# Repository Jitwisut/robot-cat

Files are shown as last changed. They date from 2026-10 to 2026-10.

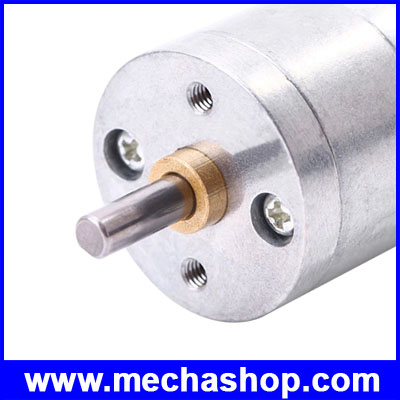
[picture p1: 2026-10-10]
robot_v4/print_revision/catalog/evidence/FromFactory_DCM068_listing_photo_2.jpg

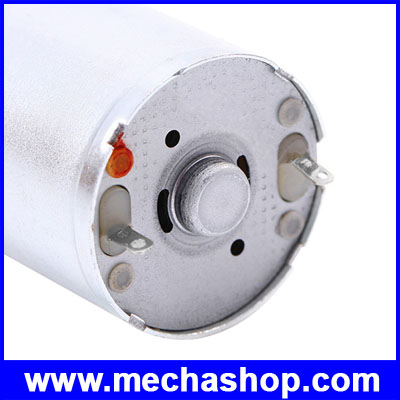
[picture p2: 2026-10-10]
robot_v4/print_revision/catalog/evidence/FromFactory_DCM068_listing_photo_1.jpg

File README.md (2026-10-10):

**Robot V4 R3 (10 ต.ค.2026):** [ชุด CAD/ทดลอง/ขอราคาและงานที่ยังต้องปิด](robot_v4/print_revision/r3/README.md) — DRAFT, ยังไม่พร้อมส่งพิมพ์ชุดเต็ม

# robot-cat — ESP32 Mini BattleBot (V2 robot2 / V3 R3)

CAD, Fusion 360 scripts and reduced-order simulations for a mini battlebot. Current direction is V4 (≤2 kg, ≤6,000 THB per the competition rules; older V2/V3 studies assumed ~1.5 kg).
Project status (Thai): [`STATUS.md`](STATUS.md).
**ทดสอบฟิสิกส์ V4 บน PC (MuJoCo + Fusion Simulation):** [`SIM_ON_PC.md`](SIM_ON_PC.md). Nothing here is cleared for manufacture yet; no 3D FEA has been solved.

| Folder | Contents |
|---|---|
| `exports/` | V2 (`robot2`) CAD exports, reports, impact screening, lifter linkage analysis (`v2_linkage_2026-09-30/`) |
| `robot_v3/` | V3 study: R1–R3 CAD (F3D/STEP), build scripts, reports, robot2 vs R3 duel model (`duel_sim/`) |
| `robot_v4/` | V4 vertical beater: CAD, sizing (`design_v4.py`), matchup screen, ESP32 firmware, status (`robot_v4/STATUS.md`), reduced-order three-way sim (`three_way_sim/`), MuJoCo 3D duel sim (`mujoco_sim/`, needs `python3 -m venv .venv && .venv/bin/pip install mujoco numpy "imageio[ffmpeg]"`) |
| `fusion_scripts/` | Fusion 360 Python scripts that built/edited `robot2`; `V2_Lifter_Stops/` adds the lifter hard stops |

## Latest CAD

**แนว Robot v4 ที่ล็อกตามคำสั่งผู้ใช้ (10 ต.ค. 2026):** Z ขึ้น, พื้น XY ที่ Z=0 ใต้ล้อ, ด้านหน้า +Y ห้ามหมุนโมเดลหรือสลับแกนเพื่อให้เข้ากับค่าเริ่มต้นของโปรแกรม เปิดไฟล์ Fusion ด้านล่างเพื่อใช้ Top/Home ที่ตรวจแล้ว ข้อกำหนดถาวรอยู่ใน [`AGENTS.md`](AGENTS.md)

| Robot | File |
|---|---|
| V4 Print R3 — approved flat Fusion view (DRAFT) | [`ROBOT_V4_PRINT_R3_FUSION_Z_UP.f3d`](robot_v4/print_revision/r3/output_R3/DRAFT/ROBOT_V4_PRINT_R3_FUSION_Z_UP.f3d) |
| V2 with lifter stops (recommended) | `exports/robot2_lifter_stops_2026-10-01.f3d` / `.step` |
| V2 as of items 1–3 | `exports/robot2_items_1_3_2026-09-24.f3d`, `exports/robot2_items_1_3_active_lifter_2026-10-01.step` |
| V3 R3 lifting wedge | `robot_v3/ROBOT_V3_R3_Lifter.f3d` / `.step` |
| V4 Print R1 (draft; measured parts and shop evidence pending) | `robot_v4/print_revision/output/DRAFT/ROBOT_V4_PRINT_R1.step` — [`print preparation`](robot_v4/print_revision/README.md) |
| V4 vertical beater (current direction) | `robot_v4/ROBOT_V4_Beater.f3d` / `.step` |

Axes differ: **V2 is Z-up, nose +Y**; **V3 files are Y-up, nose −Z**. STEP units are mm.
Other `robot2_*.f3d` files in `exports/` are earlier checkpoints; `exports/STL`, `exports/DXF` and `ESP32_Mini_BattleBot_*.step` predate the lifter.

## Re-run the models

```bash
pip install numpy matplotlib
python3 robot_v3/duel_sim/duel_sim.py
python3 exports/v2_linkage_2026-09-30/v2_linkage.py
```

Fusion scripts run from Utilities → Scripts and Add-Ins. Several older scripts write to absolute macOS paths and check for a document named `robot2`.

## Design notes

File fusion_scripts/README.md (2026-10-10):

# Fusion scripts for `robot2`

## Robot v4 R3 viewer orientation

`OrientV4PrintR3.py` sets the active `ROBOT_V4_PRINT_R3` document's Top to +Z and Home to an oblique view above the XY floor. It does not rotate or translate components and does not change global Fusion preferences. It exports a local F3D without saving to the cloud. Use `robot_v4/print_revision/r3/output_R3/DRAFT/ROBOT_V4_PRINT_R3_FUSION_Z_UP.f3d` to reopen the corrected view; a STEP import may inherit Fusion's Y-up document orientation.

Checked on 2026-10-10: all 70 occurrence transforms and assembly bounds were unchanged. Reimporting the F3D retained camera up `(0,0,1)` and showed the grid beneath the wheels. The images `ROBOT_V4_PRINT_R3_FUSION_Z_UP.png` and `ROBOT_V4_PRINT_R3_FUSION_REOPENED.png` record both checks. This fixes the viewing orientation only; R3 retains its DRAFT manufacturing status.

The current `robot2` document is saved in Fusion with the wedge lifter visible. Its seven root occurrences use identity transforms, and the document's ViewCube Top is +Z. This puts the base on Fusion's XY layout grid and makes the front/top Home view show the robot lying flat. The backup is `../exports/robot2_grid_aligned.f3d`; the checked image is `../exports/views/robot2_flat_preview.png`. The original vertical spinner and optional grabber are available as modular groups; see `../exports/Modular_Weapons_Design_2026-09-24.md`. The beater concept is archived at `../exports/robot2_beater_concept_v1.f3d`.

- RestoreOriginalVerticalSpinner.py — one-time replacement of the beater with the original 6 mm axial bar and rotation envelope.
- AddWedgeLifterOption.py — one-time creation of the 62 mm spatula, 6 mm pivot and actuator envelopes.
- AddGrabberOption.py, CutGrabberPivotBores.py — one-time optional upper jaw and pivot bore creation.
- ShowVerticalSpinnerOption.py, ShowWedgeLifterOption.py, ShowGrabberOption.py — set alternative group visibility; check the ESC holder when switching.
- `OrientRobotFlat.py`, `SaveRobotFlat.py` — one-time correction and save of the current XY-grid pose. Do not rerun them on the saved document.
- `OrientRobotToGrid.py`, `DiagnoseAlignment.py` — historical Y-up/XZ-grid trials. **Do not run on the current document**; they rotate the robot upright in the corrected Z-up view.
- CheckWedgeLifterOption.py, CheckGrabberOption.py — read-only stationary interference checks; envelopes and hidden spinner hardware are excluded as applicable.
- SaveOriginalSpinnerOption.py, SaveWedgeLifterOption.py, SaveGrabberOption.py — save robot2 and export the three F3D alternatives.

- `FingerTechSwitchRevision.py` — one-time replacement of the old switch mock; expects the old `Main_Disconnect` and posts.
- `CompetitionVariant.py` — one-time removal of the `04_Top_Hammer` group.
- `FingerTechAccessRevision.py` — one-time replacement of the 20×16 mm top-cover cutout with a Ø6 mm access hole.
- `AlignCompetitionVariant.py` — historical Y-up/XZ-grid alignment. **Do not run on the current Z-up document**.
- `generate_competition_reports.py` — reads the exported JSON snapshot and regenerates current dimensions and mass reports; it does not modify Fusion.
- `BeaterConceptRevision.py` — one-time 34 mm wide beater concept and 34 mm sweep envelope; replaces the old bar. It is guarded against rerunning.
- `CheckBeaterConcept.py` — read-only bounding boxes, mass and interference check for the beater concept.
- `SaveBeaterConcept.py` — saves `robot2` and exports the F3D archive.
- `HighlightBeaterVisual.py` — gives the beater a red appearance while retaining Aluminum 7075 mass.
- `CleanBeaterView.py`, `RestoreBeaterAlignment.py` — historical beater-view helpers; the alignment helper is for the obsolete Y-up pose.
- `ExportBeaterRotorSTEP.py` — exports only the beater rotor concept as STEP.
- `mcp_local.py`, `export_beater_check.py`, `capture_fusion_view.py` — local helpers for the Fusion MCP server on port 27182.
- `BattleBotFixes.py` — historical script for the old assembly. It refuses to run on the current competition variant.

The geometry creation and migration scripts are one-time operations. Do not rerun them on the current document. Verify geometry, interference, group transforms, visibility and saved state before replacing exports.

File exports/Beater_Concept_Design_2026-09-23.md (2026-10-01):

# Beater bar แนวตั้ง — ต้นแบบใน `robot2`

อัปเดต 2026-09-23. บันทึก `robot2` ใน Fusion แล้ว และส่งออก `robot2_beater_concept_v1.f3d`. แบบนี้เป็น **การศึกษาพื้นที่และมวล CAD** ยังไม่ใช่อาวุธพร้อมผลิตหรือหมุนทดสอบ.

อัปเดตการแสดงผล 2026-09-24: ใส่ appearance สีแดงเฉพาะ beater และซ่อนสเกตช์ที่รบกวนภาพ เพราะชิ้นนี้อยู่ใต้ฝาและระหว่างปีกหน้า จึงมองจากมุมบนได้ยาก. ภาพล่าสุดคือ `views/robot2_beater_clear_final.png`. วัสดุยังเป็น Aluminum 7075 และมวล CAD ไม่เปลี่ยน. ส่งออก F3D ใหม่หลังจัดแนว Assembly ขนานกริดแล้ว.

## สิ่งที่เปลี่ยนใน Fusion

- แทน `Spinner_Bar` เดิม (กว้างตามแกน 6 มม., มวล CAD 21.693 กรัม) ด้วย `Beater_Rotor_Concept` เป็นกรอบ beater สองรางเปิดช่องกลาง กว้างตามแกน **34 มม.** วัสดุใน CAD `Aluminum 7075` และมวล **58.166 กรัม**.
- ขนาดโรเตอร์ในแกนโลก: X = -20…14 มม., Y = 28.5…48.5 มม., Z = -107.5…-42.5 มม. เส้นผ่านศูนย์กลางกวาดตามแนวหน้า/หลังยังเป็น **65 มม.** เท่ารุ่นเดิม.
- ช่องเปิดกลางตัดทะลุโรเตอร์เพื่อให้เหลือแก้มด้านข้าง nominal 4 มม. และรางปะทะที่ปลายสองด้าน nominal 10 มม. รูเพลา Ø4 มม. เป็นเพียงรูเช็กตำแหน่งกับเพลาปัจจุบัน **ยังไม่มีข้อต่อถ่ายทอดแรงบิดที่ยืนยันได้**.
- แทน `Spinner_Sweep_Envelope` ด้วย `Beater_Sweep_Envelope` กว้าง 34 มม. ซ่อนไว้ใน Fusion; เป็น solid วิเคราะห์ **ไม่ใช่ชิ้นงาน และต้องตัดออกจากการรวมมวล**.
- เก็บ `robot2_pre_beater_concept.f3d` ไว้ย้อนกลับก่อนเปลี่ยนใบ.

## ผลตรวจจาก Fusion

| รายการ | ผล |
|---|---:|
| ช่องว่างจากขอบโรเตอร์ซ้ายถึงฐานรองซ้าย | 2.5 มม. |
| ช่องว่างจากขอบโรเตอร์ขวาถึงรอกอาวุธ | 2.0 มม. |
| จุดต่ำสุดของวงกวาดเหนือผิวบนฐาน | 1.0 มม. |
| จุดสูงสุดของวงกวาดใต้ฝาบน | 12.0 มม. |
| มวล CAD ทั้งหุ่น ไม่รวม analysis envelopes | 1,070.643 กรัม |
| เพิ่มมวล CAD จากการเปลี่ยนใบ | 36.473 กรัม |
| จำนวน bodies ที่ตรวจ | 55 |

ผล `analyzeInterference` จาก Fusion พบ 2 คู่ คือ `Beater_Sweep_Envelope` กับโรเตอร์และเพลา ซึ่งคาดหมายจากปริมาตรวิเคราะห์. **ไม่พบการซ้อนทับของชิ้นงานจริงในท่าที่จัดไว้**. ผลดิบอยู่ใน `beater_concept_check.json`.

## ไฟล์

- `robot2_beater_concept_v1.f3d` — Assembly รุ่นแนวคิด; เอกสาร `robot2` ใน Fusion บันทึกแล้ว.
- `Beater_Rotor_Concept.step` — เฉพาะโรเตอร์สำหรับแลกเปลี่ยน CAD; **ไม่ใช่ไฟล์ส่งร้านผลิต**.
- `views/robot_beater_concept_attack_side.png` — ภาพมองจากด้านอาวุธ.
- `beater_concept_check.json` — bounding boxes, มวล CAD และคู่ interference.

ไฟล์ STEP ทั้ง Assembly ของรุ่นนี้ยังไม่มี; การส่งออกทั้งโมเดลในรอบแรกไม่จบภายในเวลาที่ตั้งไว้ แต่ F3D และ STEP เฉพาะโรเตอร์ส่งออกได้.

## งานวิศวกรรมที่ต้องทำก่อนเป็นแบบผลิต

1. ออกแบบ **การยึดโรเตอร์กับเพลา** ที่ถ่ายทอดแรงบิดและรับแรงกระแทกได้; รู Ø4 มม. อย่างเดียวไม่พอ. ประเมินว่าจะคงหรือเพิ่มขนาดเพลา แล้วเลือกตลับลูกปืน/รอก/แท่นรองให้สอดคล้องกัน.
2. ตรวจความแข็งแรงของแก้ม 4 มม. และรางปะทะ 10 มม. พร้อมมุมโค้งในช่องเปิดที่ผลิตได้จริง. ออกแบบการถ่วงสมดุลและตรวจรอยร้าวหลังทดสอบ.
3. ตรวจ clearance ที่แคบ โดยเฉพาะวงกวาดเหนือฐานเพียง 1 มม. ภายใต้การงอของเพลา, ระยะประกอบ และแรงกระแทก. รัศมี 32.5 มม. ใน CAD ยังไม่รวมความคลาดเคลื่อน.
4. ยืนยันมอเตอร์อาวุธ, ESC, อัตราทด/สายพาน, เวลาเร่งและหยุด และผลต่อการบังคับเลี้ยวด้วยของจริง. ยังไม่กำหนดรอบหรือพลังงานเป้าหมายจากมวล CAD นี้.
5. เปลี่ยนชุดขับ TT, ทำ failsafe และตัวล็อกอาวุธ; ชั่งชิ้นส่วนจริงทั้งหมด. มวล CAD ไม่ใช่น้ำหนักลงแข่ง.

แนวทางเลือก beater และข้อแลกเปลี่ยนอยู่ใน `Weapon_Upgrade_Review_2026-09-23.md`. การหมุนอาวุธจริงต้องเกิดในสนามปิดที่ผู้จัดรับรอง.

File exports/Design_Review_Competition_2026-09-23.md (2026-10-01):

# ทบทวนแบบหุ่น BattleBot สำหรับแข่งของคณะ

ค้นข้อมูล 2026-09-23. ผู้ใช้แจ้งว่ายังไม่มีกติกาเป็นลายลักษณ์อักษร และอนุญาตให้เปลี่ยนแบบอาวุธได้. ใช้เป้าหมายเดิม 1.5 กก. เป็น **เป้าหมายออกแบบชั่วคราว** ไม่ใช่การรับรองว่าตรงกติกาคณะ.

## แบบที่เลือกใน CAD ตอนนี้

**ตัวถังทรงลิ่ม + ขับ 2 ล้อ + กรงจักรแนวตั้งด้านหน้าเพียงอาวุธเดียว.** ถอดค้อนบนแบบจำลองออกแล้ว เพราะเพิ่มความสูง 50 มม. เหนือฝาและเพิ่มมวล CAD 86.42 กรัม โดยยังไม่มีการยืนยันว่าระบบ servo/แขนค้อนจะรับแรงกระแทกจริงได้. โมเดลมีอาวุธที่ควบคุมได้หนึ่งชุดตามตัวอย่างกติกา Robot Battle Arena 1.5 กก. ของ MIT Media Lab กรุงเทพฯ ปี 2025 ซึ่งกำหนดอาวุธควบคุมด้วยรีโมทอย่างน้อยหนึ่งชุดและสวิตช์เปิด/ปิดมือ แต่กติกานี้ **ไม่ใช่กติกางานคณะ**. [กติกา MIT Media Lab](https://www.media.mit.edu/events/ai-robotics-competition/)

| ทางเลือก | เหมาะเมื่อ | ผลต่อแบบปัจจุบัน | ข้อสรุป |
|---|---|---|---|
| กรงจักรแนวตั้งหนึ่งชุด + ปีก/แผ่นหน้าถอดเปลี่ยนได้ | ต้องการโจมตีและคุมหน้าหุ่น | ใช้ layout เดิม ต้องเสริมเพลา/ยึดใบมีด/ตัวล็อกและแก้ชุดขับ | **เลือกเป็นรุ่นแข่งหลัก** |
| ลิ่ม + lifter แบบ servo หรือ gearmotor | สนามไม่มีตู้ป้องกันสำหรับอาวุธหมุน หรืออยากเน้นควบคุม | ต้องออกแบบคันยก/จุดหมุนใหม่ แต่ลดความเสี่ยงของอาวุธหมุน | เก็บเป็นทางเลือกสำรอง |
| กรงจักร + ค้อน + อาวุธที่สาม | ต้องการหลายบทบาท | ใช้พื้นที่ น้ำหนัก ช่องสัญญาณ และเวลาซ่อมมากขึ้น | ไม่เพิ่มในรุ่นนี้ |

การไม่เพิ่มอาวุธชิ้นที่สามเป็น **การตัดสินใจด้านแบบ** ไม่ใช่ข้อห้ามจากกติกา. สำหรับหุ่น 1.5 กก. คู่มือ Bristol Bot Builders อธิบายว่า servo เหมาะกับ lifter/grabber ส่วน brushless เหมาะกับ spinner และแนะนำให้ทำระบบขับที่ปลอดภัยก่อนเพิ่มอาวุธ. [คู่มือ BBB](https://bristolbotbuilders.com/guides/)

## จุดที่ควรเปลี่ยนถัดไป เรียงตามผลต่อการแข่ง

1. **เปลี่ยนชุดขับ TT ก่อนเพิ่มพลังอาวุธ.** TT motor ทั่วไปที่แบบใช้อยู่เป็นเกียร์พลาสติก 3–6 V; แบต 3S เต็มประมาณ 12.6 V. การตั้ง PWM ประมาณ 50% ไม่ได้ยืนยันความทนของมอเตอร์หรือเกียร์ในการชน. [สเปก TT จาก Adafruit](https://www.adafruit.com/product/3777) แนะนำมอเตอร์เกียร์โลหะ 12 V ที่ออกแบบสำหรับ beetleweight เช่น BBB Planetary 22 mm 16:1 เป็น **ตัวเลือกให้เทียบ** ไม่ใช่สั่งซื้อทันที: ผู้ผลิตระบุ 63×22×22 มม., 61 กรัม, 750 rpm ที่โหลดพิกัด/12 V และกระแส stall 4.3 A. ต้องตรวจร้านที่หาได้จริง, แรงบิด, เพลา/ล้อ และขนาด CAD ก่อนเปลี่ยนรูฐาน. [BBB 22 mm motor](https://shop.bristolbotbuilders.com/product/22mm/)
2. **จับคู่ไดรเวอร์กับมอเตอร์ใหม่.** DRV8874 carrier ที่เลือกไว้จ่ายต่อเนื่องราว 2.1 A ต่อบอร์ดและมี current regulation. ก่อนล็อก 22 mm motor ต้องทดสอบโหลด/อุณหภูมิและดูว่าการจำกัดกระแสกระทบแรงขับมากเพียงใด; หากไม่พอให้เลือกไดรเวอร์ใหม่แล้วแก้ holder/สายไฟ. [Pololu DRV8874](https://www.pololu.com/product/4035)
3. **ทำกรงจักรให้เป็นชุดผลิตและซ่อมได้.** ปัจจุบันใบมีด 65×20×6 มม., เพลา 4 มม., roll pin Ø2 และสายพาน 1:1 ยังเป็น layout; จุดยึดใบมีด/เพลา ความแข็งแรงของเพลา/ลูกปืน ความตึงสายพาน และสมดุลยังไม่ผ่านการทดสอบ. ไม่เพิ่มอัตราทดหรือมวลใบมีดจนกว่าจะตรวจกับผู้มีประสบการณ์และสนามที่มีตู้ป้องกัน.
4. **เสริมหน้าหุ่นแบบถอดเปลี่ยนได้.** ปีกหน้ากลวง 2.5 มม. ใน CAD ผลิตจาก DXF แผ่นเดียวไม่ได้. ทำแบบวิธีผลิตจริง และทดลองแผ่นหน้า/ปลายลิ่มที่เปลี่ยนง่ายหลังเห็นพื้นสนาม; อย่าใส่ปลายที่เสี่ยงเกี่ยวพื้นก่อนวัด ground clearance. คู่มือ BBB ให้ความสำคัญกับการเข้าต่ำใต้คู่แข่งและยกตัวอย่าง wedge/fork สำหรับ beetleweight. [BBB ground game](https://bristolbotbuilders.com/guides/)
5. **แก้การเข้าถึงและระบบไฟ.** ตัวเรือน FingerTech และระยะรูยึดอยู่ใน CAD แล้ว แต่ยังขาดขั้วทองแดง/สายจริง. ผู้ผลิตให้ตัวเรือน 12.7×12.7×6.35 มม., รูยึดห่าง 7.62 มม. และใช้ประแจหกเหลี่ยม 2.5 มม. [FingerTech](https://www.fingertechrobotics.com/proddetail.php?prod=ft-mini-switch-metric) ต้องตรวจระยะเอื้อมผ่านช่องฝา, ทำไฟแสดงสถานะถ้าผู้จัดกำหนด, ตรวจ failsafe และเพิ่มตัวล็อกกรงจักรที่มองเห็นง่าย. กติกา BBB 2026 ระบุตัวล็อกอาวุธ, failsafe, จุดตัดไฟที่เข้าถึงได้ และการทดสอบอาวุธในตู้/สนาม. [BBB 2026 rules](https://bristolbotbuilders.com/guides/)

## สิ่งที่เปลี่ยนแล้วและสิ่งที่ยังไม่ยืนยัน

- **เปลี่ยนแล้วใน Fusion:** ถอดค้อนบน, ใส่ตัวแทน FingerTech/adapter, จัดแนว, บันทึก, ส่งออก F3D/STEP, ตรวจ interference ท่านิ่ง.
- **ยังไม่เปลี่ยนใน CAD:** TT motor, ล้อ, DRV8874, ใบมีด/เพลา/สายพาน, ปีกหน้า, รู ESP32 ตามของจริง. การเดาขนาดหรือรูยึดของมอเตอร์ใหม่แล้วตัดฐานจะทำให้เกิดงานแก้ซ้ำ.
- **ยังไม่ผ่านการทดสอบ:** การขับ 3 นาที, ความร้อน/กระแส, การพลิกตัว, ระยะพื้น, การถอดแบต, การหยุดอาวุธเมื่อสัญญาณหาย, ความแข็งแรงจุดยึด, ความปลอดภัยของสนาม.
- **ต้องขอข้อมูลจากของจริง:** ขนาดและน้ำหนักแบตพร้อมหัวต่อ, บอร์ด ESP32, มอเตอร์/ล้อที่ซื้อ, ประเภทสนามและข้อกำหนดที่ผู้จัดประกาศภายหลัง.

หากสนามงานคณะไม่มีตู้ป้องกันอาวุธหมุนที่เหมาะสม ให้ใช้ทางเลือก **ลิ่ม + lifter** และงดหมุนกรงจักร. การมีอาวุธบนโมเดลไม่ใช่หลักฐานว่าใช้ในสนามใดก็ได้.

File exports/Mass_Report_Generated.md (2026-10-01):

# มวลรุ่นแข่ง — จาก Fusion ล่าสุด

อ้างอิง `competition_model_report.json` ซึ่งอ่านจาก `robot2` หลังถอดค้อนบน และแก้สวิตช์; สำเนารายงานก่อนแก้อยู่ที่ `Mass_Report_legacy.md`.

| รายการ | มวล CAD |
|---|---:|
| ชิ้นงานทั้งหมด ยกเว้น analysis envelope | 1034.2 g |
| Analysis envelope (ไม่ใช่ชิ้นงาน) | 24.3 g |
| รวมตาม solid ใน Fusion | 1058.4 g |

ตัวเลข CAD ของอะไหล่ที่ซื้อเป็นเพียงมวลของ solid ที่ใช้จัดวาง จึงยังใช้ยืนยันน้ำหนักลงแข่งไม่ได้. เช่นตัวแทนสวิตช์ใน CAD หนัก 1.10 g แต่ผู้ผลิตระบุของจริง 2.15 g. ต้องชั่งอะไหล่จริงพร้อมสาย, หัวต่อ, น็อต, สายพาน และตัวล็อกอาวุธก่อนล็อกน้ำหนัก.

## ตามกลุ่ม (มวล CAD รวม envelope ในกลุ่ม)

| กลุ่ม | มวล |
|---|---:|
| 01_Chassis | 458.4 g |
| 02_Drivetrain | 240.1 g |
| 03_Front_Spinner | 152.3 g |
| 05_Electronics | 140.2 g |
| 06_3D_Printed | 67.4 g |

## รายชิ้น

| ชิ้นส่วน | มวล CAD | หมายเหตุ |
|---|---:|---|
| `Base_Plate_Al` | 142.36 g |  |
| `Batt_Post_1` | 0.55 g |  |
| `Batt_Post_2` | 0.55 g |  |
| `Batt_Post_3` | 0.55 g |  |
| `Batt_Post_4` | 0.55 g |  |
| `Battery_Holder` | 10.24 g |  |
| `Battery_and_Tray` | 104.18 g |  |
| `DRV8874_A` | 0.86 g |  |
| `DRV8874_B` | 0.86 g |  |
| `Disconnect_Post_1` | 2.90 g |  |
| `Disconnect_Post_2` | 2.90 g |  |
| `ESC_Tekko32` | 2.83 g |  |
| `ESP32_DevKit` | 2.44 g |  |
| `ESP32_Dupont_Keepout_A` | 1.58 g | analysis envelope |
| `ESP32_Dupont_Keepout_B` | 1.58 g | analysis envelope |
| `ESP32_Module` | 1.51 g |  |
| `FingerTech_Mini_Switch_Envelope` | 1.10 g | ตัวแทนรูปทรง; ของจริง 2.15 g ตามผู้ผลิต |
| `FingerTech_Switch_Adapter` | 2.14 g |  |
| `Front_Wedge_L` | 71.86 g |  |
| `Front_Wedge_R` | 71.86 g |  |
| `Holder_DRV8874_A` | 1.02 g |  |
| `Holder_DRV8874_B` | 1.02 g |  |
| `Holder_ESC_Tekko32` | 2.32 g |  |
| `Holder_ESP32` | 4.45 g |  |
| `Holder_Rx_ER6` | 6.40 g |  |
| `Holder_UBEC_5A` | 4.61 g |  |
| `Left_Side_Plate_Al` | 42.86 g |  |
| `Left_Support` | 3.24 g |  |
| `Left_Wheel` | 27.90 g |  |
| `Motor_Pulley` | 4.96 g |  |
| `Rear_Panel` | 27.18 g |  |
| `Right_Side_Plate_Al` | 42.86 g |  |
| `Right_Support` | 3.24 g |  |
| `Right_Wheel` | 27.90 g |  |
| `Rx_ER6` | 17.09 g |  |
| `Spinner_Bar` | 21.69 g |  |
| `Spinner_Motor` | 48.11 g |  |
| `Spinner_Motor_Cradle` | 35.80 g |  |
| `Spinner_Shaft` | 6.41 g |  |
| `Spinner_Sweep_Envelope` | 21.10 g | analysis envelope |
| `Standoff_1` | 5.61 g |  |
| `Standoff_2` | 5.46 g |  |
| `Standoff_3` | 5.61 g |  |
| `Standoff_4` | 5.61 g |  |
| `TT_Gearbox_L` | 10.16 g |  |
| `TT_Gearbox_R` | 10.16 g |  |
| `TT_Motor_Can_L` | 61.65 g |  |
| `TT_Motor_Can_R` | 61.65 g |  |
| `TT_Motor_Clamp_L` | 2.53 g |  |
| `TT_Motor_Clamp_R` | 2.53 g |  |
| `TT_Motor_Mount_L` | 17.83 g |  |
| `TT_Motor_Mount_R` | 17.83 g |  |
| `Top_Cover` | 64.33 g |  |
| `UBEC_5A` | 9.01 g |  |
| `Weapon_Pulley` | 4.89 g |  |

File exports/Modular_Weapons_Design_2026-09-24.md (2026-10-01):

# แบบสลับอาวุธ robot2 — 2026-09-24

## สิ่งที่แก้ใน Fusion

- คืน Spinner_Bar ขนาด 6 × 65 × 20 มม. พร้อมรูเพลา Ø4 มม. และวงกวาดรัศมี 32.5 มม. มวลใบตาม CAD 21.71 กรัม.
- เพิ่ม 07_Wedge_Lifter_Option. ใบตักกว้าง 62 มม. อยู่ในช่องกลาง 70 มม. ระหว่างลิ่มเดิม; ปลายหน้าเลยฐาน 22 มม. จุดหมุน Ø6 มม. และรูเผื่อ Ø6.4 มม. ใบตักมวล CAD 23.13 กรัม; ใบตัก บอส ขารอง และแกนรวมประมาณ 41.60 กรัมก่อนเซอร์โว/น็อต. Servo_30kgcm_Envelope_Only เป็นเพียงบล็อกเผื่อพื้นที่ 40 × 40 × 30 มม.
- เพิ่ม 08_Grabber_Addon_Option ที่ซ่อนอยู่เป็นค่าเริ่มต้น. ปากบนกว้าง 60 มม. แขนข้างสองข้าง แกน Ø6 มม. รูเผื่อ Ø6.4 มม. และบล็อกเผื่อเซอร์โวตัวที่สอง. เปิดพร้อม lifter เท่านั้น.
- เมื่อดูแบบ lifter ซ่อน Holder_ESC_Tekko32 ของ spinner เพื่อเปิดพื้นที่เซอร์โว.

## ผลตรวจ

| รายการ | ผล |
|---|---|
| แนวโมเดล | ตรวจเมทริกซ์กลุ่มหลักทั้งหมดเป็น Rx −90° และตรวจภาพ Fusion |
| Lifter เทียบตัวถัง/อิเล็กทรอนิกส์ | ไม่พบ boolean overlap ภายนอกชุดในท่าที่วาด |
| ปากจับเทียบตัวถัง/lifter | ไม่พบ boolean overlap ภายนอกหลังเจาะรูแกน |
| จุดซ้อนภายใน | ใบตักกับบอส 475.5 mm³ และปากบนกับแขนข้างละ 64 mm³ เป็นตำแหน่งต่อชิ้น; บล็อกก้าน/เซอร์โวเป็น envelope ไม่ใช่อะไหล่ |

การตรวจเป็น **ท่านิ่ง**. ยังไม่มี motion joint หรือการตรวจวงกวาดตอนยก/คีบ. ยังไม่ทดสอบแรงบิด ความแข็งแรง สมดุล หรือการใช้งานจริง. มวลของบล็อก Envelope_Only ใน Fusion เป็นค่าสมมติ ห้ามรวมในงบน้ำหนัก.

## ทางเลือกอาวุธแทนค้อน

ผมแนะนำ **ปากจับเสริมบน lifter** เป็นทางเลือกถัดไปสำหรับโครงนี้ เพราะใช้ลิ่มและช่องหน้าที่มีอยู่เพื่อยก/คุมคู่ต่อสู้ โดยไม่ต้องเพิ่มชุดค้อนเหนือฝา. นี่เป็นข้อสรุปเชิงออกแบบจากพื้นที่และงานที่ทำไว้ ไม่ใช่การรับประกันว่าปากจับชนะค้อนเสมอ. [NHRL อธิบายบทบาท lifter และค้อน](https://wiki.nhrl.io/wiki/index.php/Common_Robot_Types). [คู่มือ Bristol Bot Builders](https://bristolbotbuilders.com/guides/) แนะนำ servo lifter/grabber และลิ่ม/ฟอร์กในรุ่น beetleweight. [Boom Zoom](https://forum.bristolbotbuilders.com/t/boom-zoom-a-lifter-love-affair/278) เป็นตัวอย่าง lifter เซอร์โวกับชุดหน้าถอดเปลี่ยนได้. [Data Breach](https://forum.bristolbotbuilders.com/t/data-breach-beetleweight-build/197) รายงานว่าระยะก้านและกำลัง BEC ส่งผลต่อประสิทธิภาพการยก.

หากต้องการแรงกระแทก ให้ใช้ใบหมุนแนวตั้งเดิมเป็นชุดสลับ. หากต้องการทดสอบการควบคุมก่อน ให้เริ่มลิ่ม + lifter แล้วค่อยใส่ปากจับเมื่อชั่งน้ำหนักและเลือกเซอร์โวจริง.

## งานก่อนผลิต

1. เลือกเซอร์โวจริงตามแรงบิดใช้งาน, แรงดัน, ขนาด, BEC และรูปแบบก้านต่อ แล้วทำรูยึดจริง. บล็อก CAD ไม่ใช่รุ่นสินค้า.
2. ทำบูช/ลูกปืนแกน, จุดยึดฐาน, joint และสต็อป; ตรวจตำแหน่งทุกช่วงยกและคีบว่าชนฝา ลิ่ม สาย และพื้นหรือไม่.
3. ชั่งน้ำหนักแต่ละแบบรวมแบต สาย น็อต ยาง และโครงจริง. เป้าหมาย 1.5 กก. เป็นสมมติฐานเดิมเพราะการแข่งขันคณะยังไม่ประกาศกติกา.
4. สำหรับ spinner ต้องออกแบบการส่งแรงบิดจากเพลา Ø4 มม., ลูกปืน, สายพาน และตัวล็อกอาวุธก่อนทดสอบ. ใช้กล่องป้องกันที่เหมาะกับอาวุธหมุน.

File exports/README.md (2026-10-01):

# ไฟล์แบบ robot2 ปัจจุบัน

อัปเดต 2026-09-24. robot2 ใน Fusion แสดง **ลิ่ม + lifter** และบันทึกแล้ว. เปิด/ปิดกลุ่ม 03_Front_Spinner, 07_Wedge_Lifter_Option, 08_Grabber_Addon_Option เพื่อเทียบแบบ; เปิด spinner หรือ lifter ทีละชุด.

| ไฟล์ | ความหมาย |
|---|---|
| robot2_vertical_spinner_option.f3d | ชุดใบหมุนแนวตั้งเดิมก่อนเพิ่ม lifter |
| robot2_wedge_lifter_option.f3d | แบบล่าสุด แสดงลิ่ม + lifter; ซ่อน spinner และปากจับ |
| robot2_wedge_lifter_grabber_option.f3d | แบบล่าสุด แสดง lifter + ปากจับเสริม; ซ่อน spinner |
| views/robot2_vertical_spinner_option.png | ภาพตรวจใบหมุนจาก Fusion |
| views/robot2_wedge_lifter_final.png | ภาพสุดท้ายของ lifter ที่แสดงใน Fusion |
| views/robot2_lifter_camera_corrected.png | ภาพมุมกล้องที่แก้ใหม่ เห็นฐานวางราบและลิ่มยกจากด้านหน้า/ด้านบน |
| views/robot2_wedge_lifter_grabber_option.png | ภาพตรวจ lifter + ปากจับจาก Fusion |
| Modular_Weapons_Design_2026-09-24.md | ขนาด ผลตรวจ และเหตุผลเปรียบเทียบอาวุธ |

ไฟล์ beater และรายงานก่อนหน้าเป็นจุดย้อนกลับ. ไฟล์ STL/DXF/STEP อื่นยังอิงรุ่นก่อนหน้าและไม่ได้ปรับให้เข้ากับ lifter/grabber.

ไฟล์ F3D ทั้งสามเป็นแบบจัดวางแนวคิด ยังไม่ใช่แบบส่งผลิต: ต้องเลือกเซอร์โวและชิ้นส่วนจริง, ทำข้อต่อ, ตรวจการเคลื่อนที่และน้ำหนักจริงก่อนผลิต. ดู ../STATUS.md.

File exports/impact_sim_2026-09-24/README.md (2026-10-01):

# การจำลองแรงชนเบื้องต้นของ `robot2`

วันที่ 24 ก.ย. 2026 — โมเดลฐานคือ `robot2_items_1_3_2026-09-24.f3d` และสำเนาใน Fusion ชื่อ `robot2_sim_2026-09-24`.

## ขอบเขต

ผลนี้คำนวณด้วยแบบจำลองคานไฟไนต์เอลิเมนต์ 1 มิติของใบ lifter และแบบจำลองการชน 1 องศาอิสระที่มีการครากแบบ bilinear **ยังไม่ใช่** Fusion Static Stress / Dynamic Event Simulation ของหุ่นทั้งตัว และไม่ใช่ผลทดสอบชนจริง. ใช้คัดกรองจุดเสี่ยงและเลือกกรณีที่จะส่งไปทดสอบเต็มรูปแบบ.

สมมติให้ใบกว้าง 62 มม. ยึดแน่นที่ y=74 มม. และถูกชนแนวดิ่งที่ปลาย y=112 มม. วัสดุใน CAD เป็น 6061 โดยใช้ E=68.9 GPa และค่าคราก 275 MPa; สภาพอบแข็งของวัสดุจริงยังไม่ได้ยืนยัน. ใช้มวลเทียบเท่า 1.5 กก. ชนกับคู่ต่อสู้แข็ง ไม่มีการสูญเสียที่หน้าสัมผัส และใช้ความแข็งหลังคราก 2% ของความแข็งเริ่มต้น. จำลองกรณีหน้าสัมผัสเต็ม 62 มม. และเฉพาะแถบ 10 มม. เพื่อดูความไวต่อบริเวณสัมผัส. การยึดปลายหลังแบบแน่นอาจแข็งกว่าบานพับจริง.

## ผลหลัก

| กรณี | Von Mises ที่ใบ lifter | Displacement สูงสุด | Plastic Deformation หลังชน* | Velocity / Acceleration ของมวลเทียบเท่า | ความน่าใช้ของแบบจำลอง |
|---|---:|---:|---:|---:|---|
| สัมผัสเต็ม, 0.5 m/s | 138 MPa; สูงสุดที่โคน y≈74 มม. | 0.64 มม. | 0 | 0.5 m/s / 39.6 g | ผ่านเงื่อนไขโก่งตัวเล็ก |
| สัมผัสเต็ม, 1 m/s | ถึงค่าคราก 275 MPa; ค่าจริงหลังครากไม่ทราบ | 1.29 มม. | ≈0.003 มม. | 1.0 m/s / 79.1 g | ผ่านเงื่อนไขโก่งตัวเล็ก |
| สัมผัสเต็ม, 2 m/s | หลังคราก; ค่าจริงไม่ทราบ | 3.19 มม. | ≈1.87 มม. | 2.0 m/s / 81.4 g | ใกล้ขอบการโก่งตัวเล็ก |
| สัมผัสเต็ม, 3 m/s | หลังคราก; ค่าจริงไม่ทราบ | 6.26 มม. | ≈4.87 มม. | 3.0 m/s / 85.1 g | **เกินขอบเขตแบบจำลอง** |
| สัมผัสแถบ 10 มม., 0.5 m/s | หลังคราก; ค่าจริงไม่ทราบ | 1.64 มม. | ≈0.35 มม. | 0.5 m/s / 12.8 g | ผ่านเงื่อนไขโก่งตัวเล็ก แต่ contact จริงไม่ทราบ |
| สัมผัสแถบ 10 มม., ≥1 m/s | คราก | >4.5 มม. | ค่าตัวเลขไม่ควรใช้ | ดู CSV | **เกินขอบเขตแบบจำลอง** |

\*ค่าเสียรูปถาวรเป็น **ตัวแทนจากสปริง bilinear** ไม่ใช่แผนที่ plastic strain จาก FEA 3 มิติ. ค่า Von Mises ที่ใบมาจากความเค้นดัดสูงสุดของคานในช่วงยืดหยุ่น; เมื่อคราก การกระจายความเค้นจริงต้องใช้วัสดุไม่เชิงเส้นและการสัมผัส 3 มิติ. ในไฟล์ผลลัพธ์ `elastic_equivalent_root_bending_MPa` หลังครากเป็นเพียงค่าคำนวณย้อนด้วยสมการยืดหยุ่นและมี `root_stress_model_valid=false`; ห้ามอ่านเป็น Von Mises จริง. ค่า velocity/acceleration เป็นของมวลเทียบเท่าในแบบจำลอง ไม่ใช่ของทุกชิ้นส่วนหุ่น.

แรงที่ใบเริ่มครากในแบบสัมผัสเต็ม ≈1,163 N หรือความเร็วเริ่มคราก ≈1.00 m/s ภายใต้สมมติฐานนี้. ถ้าชนเฉพาะแถบ 10 มม. แรงเริ่มครากลดเหลือ ≈188 N และความเร็ว ≈0.40 m/s. ดังนั้น **พื้นที่สัมผัสมีผลสูงมาก** และห้ามใช้เลขเดียวเป็นเกณฑ์ว่าหุ่นทั้งตัวจะพังที่ความเร็วใด.

ผมทดสอบความไวต่อ **มวลเทียบเท่า** เพิ่มที่ 0.25, 0.62 และ 1.5 กก. (`mass_sensitivity.csv`). สำหรับหน้าสัมผัสเต็มและความเร็วสัมพัทธ์ 1 m/s แรงยอดเปลี่ยนจากประมาณ 476 → 748 → 1,163 N ตามลำดับ; สองกรณีแรกไม่ถึงค่าครากของใบในแบบจำลอง. ค่า 0.62 กก. เป็น reduced mass โดยประมาณของหุ่น 1.05 กก. กับคู่ต่อสู้ 1.5 กก. เมื่อทั้งคู่เคลื่อนที่อิสระ; มวลหุ่นยังเป็นตัวเลข CAD ชั่วคราว. ผลจึงไวต่อสภาพการชนและการจับยึด ไม่ควรถือว่าทุกการชน 1 m/s ทำให้ใบคราก.

## แกน lifter และเส้นทางแรง

แกนเหล็ก Ø6 มม. ช่วงแท่นรอง 67 มม. ยังไม่ระบุเกรด/ค่าครากจริง. ถ้าสมมติเป็นคานรองรับสองปลายและแรงทั้งหมดลงกลางแกน ความเค้นดัด ≈0.790 MPa ต่อแรง 1 N และโก่ง ≈0.000492 มม. ต่อแรง 1 N. เหล็กที่คราก 250 MPa จะเริ่มครากที่ ≈317 N ตามสมมติฐานนี้. ตัวอย่างแรงชน 583 N จากกรณีใบเต็ม 0.5 m/s จะให้ ≈460 MPa **เฉพาะกรณีที่แรงทั้งหมดผ่านแกนกลาง**. การแบ่งแรงจริงผ่านบอส ขายึด และตัวรับใบยังไม่ทราบ จึงยังตัดสินว่าแกนจริงจะครากไม่ได้.

จุดที่ควรออกแบบและทดสอบเพิ่มก่อนประกอบแข่งคือโคนใบ lifter, แกนและบูช, แท่นรองแกนกับน็อต M3, รอยต่อลิ่มกับฐาน, และจุดยึดแบตเตอรี่. หากแรงชนผ่านข้อต่อเซอร์โว ต้องมีตัวรับแรง/stop เชิงกลที่ไม่ปล่อยแรงปะทะเข้าก้านเซอร์โวโดยตรง.

**การตรวจแรงบิดที่บานพับ:** ปลายใบอยู่ห่างแกนหมุน 44 มม. ถ้าไม่มี stop รับแรงไว้ แรงชน 583 N ในกรณี 0.5 m/s ข้างบนเท่ากับโมเมนต์ประมาณ **25.6 N·m** รอบแกน เทียบกับชื่อรุ่นเซอร์โว 40 kgf·cm ซึ่งเท่ากับประมาณ **3.92 N·m** เป็นอัตรา 6.5 เท่า. ชื่อรุ่นเป็นค่าแรงบิดที่ระบุ ไม่ใช่พิกัดทนแรงกระแทก และกลไกจริงอาจถ่ายแรงไปที่จุดอื่น; ตัวเลขนี้จึงเป็นเหตุให้เพิ่ม **hard stop ที่โครง** และวัดเส้นทางแรงจริง ก่อนใช้ servo รับการชน.

**กรณีชนลิ่มหน้าและด้านข้าง:** คำนวณกรอบพลังงาน/แรงเฉลี่ยไว้ใน `front_side_load_envelope.csv` สำหรับ 0.5–3 m/s และระยะหยุด 2, 5, 10 มม. เช่น มวลเทียบเท่า 1.5 กก. ที่ 2 m/s กับระยะหยุด 5 มม. มีพลังงาน 3 J และแรงเฉลี่ย 600 N; แรงสูงสุดอาจมากกว่า. ยังแปลงเป็น Von Mises ของลิ่มหรือแผ่นข้างไม่ได้ เพราะตำแหน่งสัมผัส จุดรองรับ ความแข็งของน็อต/รอยต่อ และระยะหยุดจริงไม่ทราบ. การทำ FEA โดยล็อกลิ่มกับฐานอย่างสมบูรณ์จะให้ความแข็งเกินกว่าชุดน็อตจริง.

## การตรวจความถูกต้องเชิงตัวเลข

- เพิ่มจำนวนชิ้นคาน 40 → 80: ค่าการโก่งปลายเปลี่ยน 0.0113%.
- เทียบความยืดหยุ่น FE กับอินทิกรัลคานอิสระ: ต่าง 0.00377%.
- กรณี 0.5 m/s ที่ยังไม่คราก เทียบแรงสูงสุดกับคำตอบตัวแกว่งมวล–สปริงแบบปิดรูป: ต่าง <1%; พลังงานกลับใกล้พลังงานเริ่มต้น.
- รันความไวต่อความเร็ว 0.5, 1, 2, 3 m/s และความกว้างสัมผัส 62/10 มม.; ไฟล์เวลาทุกกรณีมี F, displacement, velocity, acceleration และ plastic offset.

## สถานะ Fusion Simulation

เปิดสำเนา `robot2_sim_2026-09-24` ใน Fusion และบันทึกสำเร็จแล้ว. การเรียกคำสั่ง **New Simulation Study** ผ่าน Fusion MCP ทำให้แอปปิดตัว **สองครั้ง**. เปิดเอกสารกู้คืนขึ้นมาเพื่อตรวจซ้ำ: ใน Design workspace โมเดลและ `DesignProductType` แสดงปกติ แต่เมื่อสลับไป Simulation workspace แคนวาสว่างเปล่าและ Fusion API รายงาน `activeProduct = None` แม้ `activeDocument` ยังเป็นสำเนาเดิม. หลังเหตุขัดข้อง log ยังรายงาน `No active viewport` และ `There is no active document` ขณะปิดตัว; log ไม่ระบุสาเหตุรากที่ยืนยันได้. จึงหยุดเรียกคำสั่งที่ทำให้แอปปิดซ้ำ และคืนหน้าจอไปที่ Design workspace โดยโมเดลยังแสดงอยู่. **ยังไม่ได้สร้างหรือ Solve Study ใน Fusion** จึงไม่มีผล 3D von Mises, displacement, plastic strain, velocity/acceleration ของหุ่นทั้งตัว. ไฟล์ `robot2` ต้นฉบับและ F3D สำรองก่อนทดลองยังอยู่. ตามเอกสาร Autodesk, Dynamic Event Simulation ให้ผลทั้งห้าประเภทและใช้โทเคน; Linear Static Stress ใช้คัดกรองความเค้น/การโก่งและรวมอยู่ใน subscription. ก่อนรันเต็มรูปแบบต้องระบุเกรดวัสดุจริง, รูปแบบการยึด, contact, มวลคู่ต่อสู้, ความเร็ว และทิศชน.

แหล่งอ้างอิง: [Autodesk Dynamic Event Simulation](https://help.autodesk.com/cloudhelp/ENU/Fusion-Simulate/files/SIM-EVENT-SIM-STUDY-CONCEPT.htm), [Autodesk Event Simulation results](https://help.autodesk.com/cloudhelp/ENU/Fusion-Simulate/files/SIM-EVENT-SIM-RESULTS-CONCEPT.htm), [Autodesk Static Stress assumptions](https://help.autodesk.com/cloudhelp/ENU/Fusion-Simulate/files/SIM-STATIC-STRESS-ANALYSIS.htm), [Autodesk simulation token costs](https://help.autodesk.com/cloudhelp/ENU/Fusion-CloudCredits/files/GUID-97268379-A0C4-4426-8929-2FB3F3FB439C.htm).

ข้อมูล: [`results.json`](results.json), [`scenario_summary.csv`](scenario_summary.csv), [`mass_sensitivity.csv`](mass_sensitivity.csv), [`front_side_load_envelope.csv`](front_side_load_envelope.csv), และ `time_*.csv`; สคริปต์ที่รันซ้ำได้: [`impact_dynamic_reduced.py`](../../fusion_scripts/impact_dynamic_reduced.py).

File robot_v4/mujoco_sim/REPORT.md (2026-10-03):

# จำลอง 3D ด้วย MuJoCo: V2 vs R3 vs V4 (3–4 ต.ค. 2026)

**สิ่งที่เป็น:** จำลองฟิสิกส์ของแข็ง (rigid body) แบบ 3D ใน MuJoCo 3.14
- มีล้อ มอเตอร์ไฟฟ้ากระแสตรงที่คิดแรงต้านไฟย้อนกลับ (back-EMF) เซอร์โวที่จำกัดความเร็วตามของจริง ใบหมุน และบานพับครบทุกคัน
- ใช้หน้าสัมผัสแบบนุ่มของ MuJoCo (soft contact)
- ใบ V4 หมุนด้วยความเร็วและแรงเฉื่อยจริง ขับด้วยแบบจำลองมอเตอร์ D3536 และ ramp ของเฟิร์มแวร์

**สิ่งที่ไม่ใช่:**
- ไม่ใช่ FEA ชิ้นงานไม่บิดไม่แตก
- ไม่มีคนขับจริง ใช้ "คนขับอัตโนมัติ" กติกาเดียวกันทุกคัน
- **ความแรงที่ใบส่งให้คู่ต่อสู้ขึ้นกับค่าความแข็งของหน้าสัมผัส (`solref`) ที่ตั้งเอง** จึงรันหลายค่า และยังต้องยืนยันด้วยการทดสอบจริง

**รันซ้ำได้** (ต้องสร้าง venv ก่อน: `python3 -m venv .venv && .venv/bin/pip install mujoco numpy "imageio[ffmpeg]"`):

| สคริปต์ | ทำอะไร | ไฟล์ผลลัพธ์ |
|---|---|---|
| `validate.py` | ตรวจโมเดลรถทีละคัน | `validation.json` |
| `convergence.py` | ตรวจ timestep | `convergence.json` |
| `run_duels.py 24` | ปะทะ 576 ครั้ง (ประมาณ 7 นาทีบน 8 คอร์) | `duels.json` |
| `flank_test.py` | ชนข้างและท้าย V4 | `flank_test.json` |
| `skirt_variants.py`, `skirt_tolerance.py` | เทียบ skirt หลายแบบ | |
| `centre_wedge_test.py`, `bite_test.py`, `tooth_test.py`, `attack_angle_test.py` | ทางแก้ข้อ "ลิ่มมุดใต้ใบ" | |
| `render.py` | เรนเดอร์คลิป | `clips/*.mp4` |

## สิ่งที่การจำลองเจอใน V4

| ปัญหา | สาเหตุ | ผล |
|---|---|---|
| **skirt แบกน้ำหนักรถแทนล้อ** (≈16 จาก 18.6 N) จนดันได้แค่ 2–4 N | แผ่นที่ห้อยตรงทำตัวเป็นเสาค้ำ แรงเสียดทานกับพื้นกันไม่ให้ขอบล่างไถลออก | **แก้แล้ว** (ดูหัวข้อ skirt) |
| **ลิ่มของ R3 มุดใต้ข้างและท้ายได้** (69–100%) | skirt บานพับ: ปลายลิ่มสอดเข้าใต้ขอบแล้วงัดแผ่นขึ้นได้ | **แก้แล้ว:** เปลี่ยนเป็น skirt ยึดตายเอียง 35° สูงจากพื้น 0.5 มม. ตอนนี้มุดได้ 0% |
| **ตอนเร่งใบ หัวรถทิ่มจนฟันตีพื้น** | V4 หน้าหนัก จุดศูนย์ถ่วงอยู่หลังเพลาหน้าแค่ประมาณ 1 มม. แรงบิดสะท้อน (≈0.2 N·m) จึงมากกว่าแรงกันทิ่มจากน้ำหนัก (≈0.02 N·m) | **แก้แล้ว:** เพิ่ม nose skid UHMW สูงจากพื้น 1 มม. หัวทิ่มได้ไม่เกินประมาณ 0.9° แล้วฟันยังห่างพื้น |
| **V4 หน้าหนัก** ล้อหลังรับน้ำหนักแค่ประมาณ 5% ดันได้ 8.5 N จากที่ควรได้ 11 N | ใบ มอเตอร์อาวุธ และแผ่นตั้ง อยู่หน้าทั้งหมด | ยังไม่ได้แก้ |
| **ใบของ V4 งัดลิ่มลาดของ R3 ไม่ได้** | ดูหัวข้อ "ใบเจอลิ่มต่ำ" | ลองแก้ 4 ทาง ไม่มีทางไหนได้ผล จึงยังไม่เปลี่ยนแบบ |

**บั๊กในโมเดลจำลองเองที่เจอและแก้แล้ว:**
- ฟันที่จำลองเป็นกล่องเดียวมีมุมกวาดรัศมีถึง 31.8 มม. แล้วขูดพื้น (ฟันจริงยาว 29.5 มม.) แก้เป็นกล่องแคบ 2 ชิ้นต่อฟัน
- เซอร์โวของ lifter ไม่ได้จำกัดความเร็ว จึงสะบัดเหมือนตัวพลิก (flipper) จน R3 พลิก V4 คว่ำได้ แก้เป็น 60° ต่อ 0.16 วินาทีตามเซอร์โวจริง แล้วรันใหม่ทั้งหมด

## Skirt: เลือกแบบจากการจำลอง

**วิธีทดสอบ (`flank_test.py`):**
- V4 จอดนิ่ง ให้ V2 หรือ R3 พุ่งชนข้างหรือท้ายที่คันเร่งเต็ม lifter ทำงานตามปกติ
- นับว่า "มุดใต้ได้" เมื่อล้อ V4 รับน้ำหนักน้อยกว่า 25% นานเกิน 0.25 วินาที หรือ V4 เอียงเกิน 5°

**ผลแต่ละแบบ** (`skirt_variants.py`; ตัวเลขคือ R3 ชนข้าง / R3 ชนท้าย / V2 ชนข้าง / V2 ชนท้าย, และแรงดันของ V4):

| แบบ skirt | มุดใต้ได้ | V4 ดันได้ | ล้อรับน้ำหนักตอนพัก |
|---|---|---:|---:|
| ไม่มี skirt | 100% / 100% / 0% / 29% | – | – |
| บานพับเอียง 35° | 66% / 100% / 0% / 0% | 7.8 N | 98% |
| บานพับ จำกัดยก 5° | 66% / 100% / 0% / 0% | 8.0 N | 98% |
| บานพับ + สปริง | 0% / 0% / 0% / 0% | **6.6 N, เลี้ยวช้าลง 27%** | **80%** |
| **ยึดตาย สูง 0.5 มม. (เลือกแบบนี้)** | **0% / 0% / 0% / 0%** | **8.5 N** | 99% |
| ยึดตาย สูง 1.0 มม. | 0% / 0% / 0% / 0% | 8.0 N | 99% |

**ความคลาดเคลื่อนตอนประกอบจริง** (`skirt_tolerance.py`; สุ่มความสูงขอบ):
- สูง 0–1.5 มม.: มุดใต้ได้ 0% ทุกกรณี
- สูง 1.5–2.5 มม.: R3 มุดได้ 29% เฉพาะตอนชนท้าย

แนบท้ายคู่มือผลิต: ทำรูยึดเป็นร่องเพื่อปรับความสูงให้ได้ 0.5 มม. บนพื้นสนามจริง

## ใบเจอลิ่มต่ำ: ลองแก้ 4 ทาง (ไม่ได้ผล)

ทุกทางทดสอบแบบเดียวกัน: V4 ใบหมุนเต็มรอบ พุ่งชนหน้าตรงๆ ทางละ 16–24 ครั้ง แล้วนับว่าคู่ต่อสู้ลอยเกิน 10 ซม. กี่ %

| ทางแก้ | R3 ลอย | V2 ลอย (V2 วิ่งเข้ามาด้วย) | หมายเหตุ |
|---|---:|---:|---|
| แบบปัจจุบัน | 0–6% | 62% | |
| wedgelet บานพับตรงกลางระหว่างจาน | 0% | ไม่ชัดเจน | ไม่ช่วย และหนักขึ้น 25 กรัม |
| มอเตอร์ล้อเร็วขึ้น (620 rpm) | 6% | 62% | ไม่ช่วย |
| ทดรอบใบลง 1.5:1 (bite มากขึ้น) | 0% | **88%** | ช่วยเฉพาะตอนเจอ V2 แต่พลังงานใบลดเหลือประมาณครึ่ง |
| ลดระยะฟันกับพื้นเหลือ 1.5 มม. + ลด nose skid เหลือ 0.5 มม. | 0–6% | 44% | ไม่ช่วย |

**ถ้าคู่ต่อสู้จอดนิ่ง ใบแทบไม่ทำให้ใครลอยเลย ทุกแบบ** (`attack_angle_test.py` ทั้งด้านหน้า ข้าง และท้าย)

**ข้อสรุป:**
- ใบหมุนแนวตั้งต้องมีขอบที่ฟันงัดเข้าไปข้างใต้ได้
- ลิ่มลาด 25° ของ R3 และใบตักของ V2 ตอนจอดนิ่ง (หัวคว่ำ สูง 2.1 มม.) ทำให้ฟันได้แค่ปัดผิว
- V2 ลอยได้ก็ต่อเมื่อวิ่งเข้ามา เพราะตอนเร่ง V2 เงยหน้า ใบตักยกขึ้นไปที่ 9.5 มม.

**จึงไม่เปลี่ยนแบบในรอบนี้** ถ้าต้องการให้ใบได้ผลกับลิ่ม ต้องเปลี่ยนแนวคิดอาวุธ (เช่นใช้ใบหมุนแนวตั้งที่ใหญ่และช้าลง มีฟันน้อยลง) ซึ่งเป็นงานใหญ่

## ตรวจโมเดลแต่ละคัน (`validation.json`, μ 0.6)

| | V2 | R3 | V4 |
|---|---|---|---|
| มวล (กก.) | 1.087 | 1.237 | 1.889 |
| จุดศูนย์ถ่วง (หน้า, สูง มม.) | 3.4, 29.7 | 16.1, 15.0 | 8.6, 29.5 |
| ขอบต่ำสุดตอนพัก | ใบตัก 2.06 / แผ่นฐาน 0 (หน้าคว่ำ 1.9°) | ปลายลิ่ม 1.0 / การ์ดข้าง 6.0 | wedgelet 0 / skirt 0.5 / nose skid 1.0 / พื้นถาด 4.0 |
| ความเร็วสูงสุด | 1.60 m/s | 1.59 m/s | 1.05 m/s |
| แรงดันผนัง / แรงสูงสุดจากการยึดเกาะ | 6.1 / 6.4 N | 7.5 / 7.3 N | 8.5 / 11.1 N |
| เวลาหมุน 90° (ค่าจากแบบลดรูป) | 0.25 วิ (0.20) | 0.41 วิ (0.45) | 0.44 วิ (0.36) |
| ขับกลับหัว 1.5 วินาที | 0 ม. (**วิ่งไม่ได้**) | 1.38 ม. | 1.37 ม. |
| ไจโร (ใบหมุนเต็มรอบ แล้วเลี้ยวสุดโดยไม่จำกัดอัตราเลี้ยว) | – | – | เลี้ยวได้สูงสุด 9.0 rad/s ล้อยังไม่ยก ตัวจำกัดอัตราเลี้ยวในเฟิร์มแวร์จึงไม่เคยทำงาน |
| รอบใบตัวเปล่า | – | – | 13,780 rpm ≈ 71 J |

## ตรวจ timestep (`convergence.json`)

ค่ากลางของความสูงสูงสุดที่จุดศูนย์ถ่วงของคู่ต่อสู้ขึ้นไปถึงตอนชนหน้า (24 ครั้งต่อค่า):

| | dt 4×10⁻⁵ | **dt 2×10⁻⁵ (ใช้ค่านี้)** | dt 1×10⁻⁵ |
|---|---:|---:|---:|
| V2, solref 0.004 | 220 มม. | 225 | 192 |
| V2, solref 0.002 | 144 | 153 | 108 |
| R3, solref 0.004 / 0.002 | 28 / 24 | 28 / 24 | 27 / 24 |

- dt 2×10⁻⁵ นิ่งพอเมื่อเทียบกับความแกว่งระหว่างแต่ละครั้งที่สุ่ม
- **ความแข็งของหน้าสัมผัส (solref) มีผลมากกว่า timestep** (ทำให้ V2 ลอยต่างกันได้ประมาณ 1.5 เท่า)

## ผลการปะทะ (`duels.json`; V4 แบบสุดท้าย)

**วิธีรัน:**
- สุ่มจุดเริ่มห่างกัน 0.5–1.0 ม. หันหน้าแบบสุ่มมีความคลาด
- ทั้งสองคันใช้คนขับอัตโนมัติแบบเดียวกัน คือหันเข้าหาแล้วพุ่งชน ปะทะครั้งละ 6 วินาที
- V4 เร่งใบจากหยุดนิ่ง
- เปลี่ยนค่า 3 ตัว อย่างละ 2 ค่า: μ 0.4 / 0.8, solref 0.004 / 0.002, สนาม 2.4 / 1.5 ม. รวม 8 ชุด ชุดละ 24 ครั้ง ต่อคู่
- ไม่มีครั้งไหนที่โมเดลพัง

| คู่ (A vs B) | A ได้เปรียบ (ต่ำสุด / กลาง / สูงสุด ของ 8 ชุด) | B ได้เปรียบ | ไม่มีใครได้เปรียบ | หมายเหตุ |
|---|---|---|---|---|
| **V4 vs V2** | **12% / 35% / 58%** (ทำให้หมด 0–29%) | **0% ทุกชุด** | 42–88% | V2 ลอยเกิน 10 ซม. ใน 17% ของการปะทะ จบแบบคว่ำ 6% |
| **V4 vs R3** | **8% / 27% / 83%** | 0–4% | 17–92% | R3 ไม่ลอยเลย ในครั้งที่ V4 ได้เปรียบ ล้อ R3 รับน้ำหนักน้อย (น่าจะเป็นตอน V4 ขึ้นไปอยู่บนลิ่มของ R3) และถูกดันติดผนัง |
| **V2 vs R3** | 0% | **R3 96–100%** (ทำให้หมด 54–67%) | 0–4% | R3 มุดใต้ V2 แล้วยกจนล้อลอยนานเกิน 2 วินาที |

- **ขนาดสนามมีผลมาก:** V4 vs R3 ได้เปรียบ 58% ในสนาม 1.5 ม. เหลือ 14% ในสนาม 2.4 ม.
- **กระแสอาวุธ V4:** ค่ากลางสูงสุด 29 A ต่อการปะทะ สูงสุดทั้งหมด **224 A** ตอนใบถูกหยุดกะทันหันขณะคันเร่งเต็ม ต้องวัดของจริง และคิดเรื่อง ESC กับสายพานที่ลื่นได้

## เทียบกับแบบจำลองลดรูป (`three_way_sim`)

| คู่ | แบบลดรูป | 3D | สอดคล้องกันไหม |
|---|---|---|---|
| V4 vs V2 | V4 ชนะ 90–100% (หลัก) / 42–71% (มองแง่ร้าย) | V4 ได้เปรียบ 12–58% **V2 ไม่เคยได้เปรียบ** | ทิศทางตรงกัน แต่ใน 3D V2 คว่ำน้อยกว่ามาก (6% เทียบกับที่สมมติไว้ 30–70%) |
| V4 vs R3 | V4 ชนะ 96–100% / 89–100% | V4 ได้เปรียบ 8–83%, R3 ได้เปรียบ 0–4% | ทิศทางตรงกัน **แต่กลไกต่างกัน**: ใน 3D ใบตี R3 ไม่ได้ผล V4 ชนะด้วยน้ำหนักและการดัน |
| V2 vs R3 | R3 ชนะ 33–94% | R3 ได้เปรียบ 96–100% | ตรงกัน |

**ส่วนที่ต่างกัน:**
1. **แบบลดรูปประเมิน skirt บานพับดีเกินจริง** เพราะมองไม่เห็นว่าแผ่นจะยกตามลิ่ม
2. **แบบลดรูปประเมินใบดีเกินจริงเมื่อเจอขอบต่ำ** เพราะไม่ได้คิดเรื่อง bite
3. **ใน 3D ทุกคันชนหน้ากันเป็นส่วนใหญ่** เพราะคนขับอัตโนมัติไม่ได้พยายามอ้อมไปด้านข้าง **ข้อนี้เข้าข้าง V4 และ R3**
4. แบบลดรูปนับทั้งแมตช์ ส่วน 3D นับการปะทะ 6 วินาทีครั้งเดียว ตัวเลขจึงเทียบกันได้แค่ทิศทาง

## สิ่งที่ควรทำต่อ

1. **ทดสอบจริงที่ตัดสินผลทั้งหมด:**
   - ให้ใบตีลิ่มเหล็กที่ต่ำ 1 มม. ทั้งตอนลิ่มจอดนิ่งและตอนวิ่งเข้ามา แล้ววัดว่ากระเด็นสูงแค่ไหน
   - ตั้ง skirt ให้สูง 0.5 มม. บนพื้นจริง
   - ชั่งหาจุดศูนย์ถ่วงจริงของรถ
2. **V4 หน้าหนัก:** ถ้าจุดศูนย์ถ่วงจริงใกล้เพลาหน้าแบบนี้ ต้องพิจารณาจัดวางชิ้นส่วนใหม่
3. **อาวุธเจอลิ่ม:** ถ้าในการแข่งมีหุ่นลิ่มเยอะ ให้พิจารณาทดรอบใบ 1.5:1 (งัดได้ดีขึ้น แต่พลังงานลดลง) หรือออกแบบอาวุธใหม่

## สมมติฐาน

| เรื่อง | ค่าที่ใช้ | หมายเหตุ |
|---|---|---|
| **คนขับอัตโนมัติ** | หันเข้าหาอีกฝ่ายแล้วพุ่งชน; lifter ยกเมื่ออีกฝ่ายอยู่ด้านหน้าในระยะ 17 ซม.; V4 ใช้ตัวจำกัดอัตราเลี้ยว 12 rad/s; คันที่กลับหัวได้ให้กลับทิศคันเร่งเอง | **สมมติฐานใหญ่ที่สุด** คนขับจริงจะอ้อมไปด้านข้างและหนีได้ |
| รูปทรง | กล่อง ทรงกระบอก และแผ่นลาด จากตัวเลขใน `duel_sim` (V2, R3) และ `build_robot_v4.py` (V4) | ไม่ได้ใช้ STEP โดยตรง |
| ความแข็งของหน้าสัมผัส | solref 0.004 และ 0.002 | **ตัวที่ทำให้ใบส่งพลังงานได้ต่างกัน** |
| แรงเสียดทาน | ยาง 0.4 / 0.8 กับพื้น; ชิ้นแข็ง 0.3; UHMW 0.15 | |
| มอเตอร์ล้อ | DC + back-EMF ตาม `duel_sim` / `design_v4` | ไม่ได้คิดกระแสจำกัดของ DRV8871 / ESC |
| ใบ V4 | I จาก `design_v4.py`, D3536 Ke/R/I0, ramp 1,600 µs/s, ไม่จำกัดกระแส | สายพานลื่นไม่ได้จำลอง |
| เซอร์โว lifter | 60° ต่อ 0.16 วินาที, แรงบิดสูงสุด 3 N·m (V2) / 4 N·m (R3) | |
| จุดศูนย์ถ่วง V4 | y +8.7 มม. (ประมาณจากน้ำหนักชิ้นส่วนใน CAD ทีละชิ้น ไม่ได้มาจาก Fusion) | เป็นตัวที่ทำให้พบว่า V4 หน้าหนัก ต้องมี nose skid และดันได้น้อยลง; `three_way_sim` ใช้ +5 มม. |
| จำนวนรอบที่รัน | 24 ครั้งต่อชุด (ทดสอบชนข้าง 48/24, ทางแก้ 16–24) | ตัวเลขแต่ละชุดคลาดได้ประมาณ ±10% |
| ผลแพ้ชนะ | **ทำให้หมด** = V2 คว่ำค้างเกิน 1.5 วินาที หรือล้อรับน้ำหนักไม่ถึง 25% ต่อเนื่องเกิน 2 วินาที; **คุม** = เวลาที่อีกฝ่ายถูกยกเกิน 0.25 วินาทีต่อครั้ง หรือถูกดันติดผนัง มากกว่าอีกฝ่ายเกิน 0.5 วินาที | แบ่งกลุ่มเหมือน `three_way_sim` |

## คลิป (`clips/`)

| ไฟล์ | เนื้อหา |
|---|---|
| `v4_vs_v2_headon_slowmo.mp4` | V4 ชนหน้า V2 ใบหมุนเต็มรอบ ภาพช้า 8 เท่า: V2 ลอยหมุนกลางอากาศ |
| `v4_vs_r3_headon_slowmo.mp4` | V4 ชนหน้า R3 ภาพช้า 8 เท่า: ลิ่ม R3 มุดใต้ช่องใบ V4 ไถลขึ้นไปบนลิ่ม |
| `v4_vs_v2_engagement.mp4` | ปะทะ 6 วินาทีด้วยคนขับอัตโนมัติ |
| `v2_vs_r3_engagement.mp4` | R3 ทำให้ V2 ขยับต่อไม่ได้ |

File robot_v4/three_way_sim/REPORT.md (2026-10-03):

# จำลองการต่อสู้ V2 vs V3 (R3) vs V4 — 3 ต.ค. 2026

**ประเภทการจำลอง:** แบบลดรูป (reduced-order) + Monte Carlo + แบบจำลองแมตช์ **ไม่ใช่ฟิสิกส์ 3D และไม่มีคนขับจริง**
รันซ้ำได้ด้วย `python3 three_way.py` ผลดิบอยู่ใน `results.json`

- ใช้ตัวจำลองเดิมของ V2 vs R3 (`robot_v3/duel_sim`) ซ้ำ ส่วน V4 ใช้รูปทรงจาก `build_robot_v4.py` และค่าพลังงานใบจาก `v4_design.json`
- **เทียบหุ่นตามที่สร้างจริง ไม่ใช่ตามที่แนะนำให้แก้:**
  - V2 หนัก 1.09 กก. และ R3 หนัก 1.24 กก. ออกแบบไว้ตามเป้าเดิม 1.5 กก.
  - V4 หนัก 1.89 กก. ออกแบบตามกติกาใหม่ 2 กก.
  - R3 ยังไม่ได้ใส่ skirt จึงแยกแสดง "R3 + skirt" เป็นอีกแถว
- **พื้นสนามเป็นพลาสติก/กระเบื้อง:** ทุกคันใช้แรงเสียดทาน μ 0.4–0.8 เท่ากัน (ตัวจำลองเดิมใช้ 0.6–1.0)
- **แรงยกของ V2** ใช้ค่าจากการคำนวณก้านต่อจริง 44–80 N (`exports/v2_linkage_2026-09-30`) แทนช่วงเดา 30–150 N แบบเดิม

## ตรวจว่าใช้ตัวจำลองเดิมซ้ำได้ถูกต้อง

เมื่อใส่ค่าตั้งต้นเดิม ตัวจำลองต้องให้ผลตรงกับ `robot_v3/duel_sim/results.json`:

| ค่า | รันใหม่ | ผลเดิม |
|---|---:|---:|
| R3 คุมการชนหน้าได้ | 0.962 | 0.962 |
| V2 มุดใต้ข้าง R3 ได้ | 0.940 | 0.940 |

ตรงกันทุกค่า หลังจากนั้นจึงเปลี่ยนเป็นค่าแรงเสียดทานของพื้นสนามใหม่

## ข้อมูลพื้นฐานของแต่ละคัน

| | V2 | R3 | V4 |
|---|---:|---:|---:|
| มวล | 1.09 กก. | 1.24 กก. | 1.89 กก. |
| เวลาหมุนตัว 90° (ใช้แบบจำลองการเลี้ยวเดียวกัน, μ 0.6) | **0.20 วิ** | 0.45 วิ | 0.36 วิ |
| ความสูงขอบหน้า | ใบตัก 2.1 มม., ลิ่มข้างแตะพื้น 0 มม. (ตอนกระแทก) | 0.5–1.5 มม. | wedgelet 0.5–1.5 มม., ช่องใบ 2.5 มม. |
| ความสูงขอบข้าง/ท้าย | 0–6 มม. | การ์ด 6 มม. + ยางที่มุมเปิดโล่ง | **4 มม.** (ใต้พื้นถาด) |
| อาวุธ | lifter ยกปลายได้ 44 มม. | ลิ่มยก 36 มม. | beater ≈57 J |

- **V4:** ตอนหมุนครบ 90° อัตราหมุนยังอยู่ที่ประมาณ 8.7 rad/s จึง**ไม่ถึง**ขีดจำกัดอัตราเลี้ยว 12 rad/s (690°/s) ที่ตั้งไว้ในเฟิร์มแวร์
- **R3:** รายงานเดิมได้ 0.39 วิ ที่ต่างกันเพราะรอบนี้ใช้ μ 0.6 แทน 0.8 ไม่ได้ขัดกัน

**มีใครพลิก V4 ได้ไหม?** ต้องเอียง V4 ถึง 70° คือยกขอบข้างขึ้นประมาณ **165 มม.** แต่ V2 ยกได้แค่ 44 มม. และ R3 ได้ 36 มม.
**จึงไม่มีคันไหนพลิก V4 ได้** ทำได้แค่ยกด้านข้างให้ล้อลอย ซึ่งนับเป็นการคุมเกม ไม่ใช่ชนะเด็ดขาด (V4 ขับกลับหัวได้อยู่แล้ว)

## ผลแต่ละสถานการณ์ (สมมติฐานหลัก)

ตัวเลขในตารางคือโอกาสต่อการปะทะ 1 ครั้ง:
- **ทำให้หมด** = อีกฝ่ายขยับต่อไม่ได้
- **คุม** = ยกอีกฝ่ายลอย ดันชนะ หรือตีโดนแต่อีกฝ่ายไม่คว่ำ
- เลขที่เหลือไปจนครบ 100% คือ "ไม่มีใครได้เปรียบ"

**V4 vs V2**

| สถานการณ์ | V4 ทำให้ V2 หมด | V4 คุม | V2 คุม |
|---|---:|---:|---:|
| ชนหน้า | 48% | 48% | 4% |
| V4 ชนข้าง/ท้าย V2 | 50% | 50% | 0% |
| **V2 ชนข้าง/ท้าย V4** | 0% | 0% | **98%** |

- ใบ V4 ตีใบตักของ V2 แล้วทำให้ lifter ของ V2 พังได้ประมาณ 39% ต่อการชนหน้า 1 ครั้ง
- **แต่ lifter พังแล้ว V2 ก็ยังคุมได้เท่าเดิม** เพราะลิ่มข้างของ V2 เป็นแบบติดตายสูง 0 มม. ยังมุดใต้ขอบ 4 มม. ของ V4 ได้ ทำให้ล้อ V4 รับน้ำหนักน้อยลงและแพ้การดัน
- ตีแล้ว V2 ลอยเฉลี่ยประมาณ 0.75 ม.
- V2 วิ่งกลับหัวไม่ได้ ถ้าคว่ำคือแพ้ทันที

**V4 vs R3**

| สถานการณ์ | V4 ทำให้ R3 คว่ำ | V4 คุม | R3 คุม |
|---|---:|---:|---:|
| ชนหน้า | 47% | 48% | 5% |
| V4 ชนข้าง/ท้าย R3 | 50% | 50% | 0% |
| **R3 ชนข้าง/ท้าย V4** | 0% | 0% | **100%** |

R3 คว่ำแล้วยังขับได้ แต่ลิ่มยกลอยพ้นพื้น จึงมุดใต้อะไรไม่ได้และยกไม่ได้ นับว่า R3 เสียอาวุธ ไม่ใช่แพ้ทันที

**V2 vs R3** (ใช้ตัวจำลองเดิม บนพื้นใหม่)

| สถานการณ์ | V2 คุม | R3 คุม |
|---|---:|---:|
| ชนหน้า | 5% | 95% |
| V2 ชนข้าง R3 | 94% (ถ้า R3 ใส่ skirt: 17%) | 0% |
| R3 ชนข้าง V2 | 0% | 89% |
| V2 ชนท้าย R3 | 100% (ยางหลังของ R3 เปิดโล่ง) | 0% |
| R3 ชนท้าย V2 | 0% | 52% |

## ผลทั้งแมตช์

**วิธีคิด:**
- 1 แมตช์มีการปะทะ 4–10 ครั้ง
- สัดส่วนการชนหน้าอยู่ที่ 30–70% ส่วนที่เหลือเป็นการชนข้าง/ท้าย แบ่งให้คันที่เลี้ยวเร็วกว่าได้มากกว่า (ข้าง 70%, ท้าย 30%)
- ถ้าทำให้อีกฝ่ายหมดได้ แมตช์จบทันที ไม่อย่างนั้นใช้แต้มคุมเกมตัดสิน
- รันทุกชุดค่าใน 9 ชุด แล้วรายงานเป็น **ค่าต่ำสุด / ค่ากลาง / ค่าสูงสุด**

| คู่ | ชนะ (ต่ำสุด / กลาง / สูงสุด) | แพ้ | หมายเหตุ |
|---|---|---|---|
| **V4 vs V2** | **V4 77% / 94% / 100%** | V2 0–14% | ส่วนใหญ่ชนะเพราะ V2 คว่ำ (ค่ากลาง 91% ของแมตช์) |
| **V4 vs R3** | **V4 77% / 94% / 100%** | R3 0–8% | ชนะด้วยแต้ม เพราะ R3 คว่ำแล้วยังขับได้ แค่เสียอาวุธ |
| V2 vs R3 (R3 ตามที่สร้าง) | V2 2% / 16% / 46% | **R3 33% / 63% / 94%** | V2 ชนะได้เฉพาะเมื่อได้ชนข้างหรือท้ายบ่อย |
| V2 vs R3 (R3 + skirt) | V2 0–18% | **R3 63% / 87% / 99%** | |

### กรณีมองแง่ร้ายสำหรับ V4

สมมติให้ใบส่งพลังงานได้น้อยลงมาก:
- ชนตรงๆ ส่งพลังงาน 10–25%
- ตอนที่อีกฝ่ายมุดใต้ wedgelet แล้ว เหลือแค่ 1–5%
- คู่ต่อสู้ตกลงมาคว่ำแค่ 10–30%
- ต้องลอยเกิน 0.6 ม. จึงนับว่าตีโดน

| คู่ | V4 ชนะ (ต่ำสุด / กลาง / สูงสุด) | คู่ต่อสู้ชนะ |
|---|---|---|
| V4 vs V2 | 12% / 23% / 41% | **V2 57% / 73% / 81%** |
| V4 vs R3 | 34% / 46% / 58% | R3 33–39% |

### V4 + skirt บานพับ (เพิ่ม 4 ต.ค. ตามที่สร้างใน CAD แล้ว)

ใช้ขอบข้างและขอบท้ายของ V4 ≈0 มม. (σ 0.3) จาก skirt ที่ห้อยแตะพื้น ส่วนการชนหน้าเหมือนเดิม

| คู่ | สมมติฐานหลัก: V4 ชนะ | มองแง่ร้าย: V4 ชนะ | มองแง่ร้าย: คู่ต่อสู้ชนะ |
|---|---|---|---|
| V4 + skirt vs V2 | 89% / 99% / 100% | 14% / 27% / 49% | **V2 44% / 66% / 79%** |
| V4 + skirt vs R3 | 95% / 100% / 100% | **45% / 62% / 83%** | R3 10–34% |

**ผลของ skirt:**
- **เจอ R3:** ช่วยชัดเจน ในกรณีมองแง่ร้าย V4 พลิกจากสูสีกลายเป็นได้เปรียบ (46% → 62%)
- **เจอ V2:** ช่วยน้อย (V2 ชนะลดจาก 73% เหลือ 66%) เพราะ V2 ยังได้เปรียบจาก**การชนหน้า** ลิ่มข้างของ V2 ที่แตะพื้น 0 มม. มุดใต้ wedgelet ของ V4 (0.5–1.5 มม.) ได้
- **ขั้นต่อไปที่ควรแก้** คือทำ wedgelet ให้แตะพื้นด้วย เช่นแบบบานพับ

### V4 ตามที่สร้างตอนนี้: skirt บานพับ + wedgelet บานพับ (4 ต.ค.)

ขอบหน้าช่วง wedgelet ≈0 มม. (σ 0.3) ส่วนช่องใบยังสูง 2.5 มม. และขอบข้าง/ท้าย ≈0 มม. (σ 0.3)

| คู่ | สมมติฐานหลัก: V4 ชนะ | มองแง่ร้าย: V4 ชนะ | มองแง่ร้าย: คู่ต่อสู้ชนะ |
|---|---|---|---|
| **V4 ตอนนี้ vs V2** | 90% / 99% / 100% | **42% / 55% / 71%** | V2 21% / 32% / 40% |
| **V4 ตอนนี้ vs R3** | 96% / 100% / 100% | **89% / 97% / 100%** | R3 0–3% |

**ผลของ wedgelet บานพับ:**
- **เจอ R3:** V4 ชนะแทบทุกแมตช์แม้ในกรณีมองแง่ร้าย เพราะ R3 แทบมุดใต้ขอบหน้าไม่ได้ (โอกาสที่ R3 คุมการชนหน้า ลดจาก 58% เหลือ 11%)
- **เจอ V2:** กรณีมองแง่ร้ายพลิกจาก V2 ชนะ 66% เป็น **V4 ชนะ 55%** แต่ลิ่มข้างของ V2 ที่สูง 0 มม. ยังมุดใต้ขอบที่สูง ≈0 มม. ได้บางครั้ง จึงยังไม่ขาดลอย

**ตัวเลขนี้ขึ้นอยู่กับสมมติฐานว่าแผ่นบานพับแตะพื้นจริง** (σ 0.3 มม.) ถ้าแผ่นเด้งหรือถูกเศษบนพื้นค้ำไว้ ผลจะแย่ลงไปทางแถว "V4 + skirt" ด้านบน ต้องวัดความสูงปลายบนพื้นสนามจริง

**ผลพลิกได้ทั้งหมด** ขึ้นอยู่กับคำถามเดียว: **ใบของ V4 ยังตีได้แรงไหม ตอนที่ลิ่มต่ำของคู่ต่อสู้มุดเข้าใต้ wedgelet ไปแล้ว**
ถ้าตีได้แรง V4 ชนะทั้งสองคันอย่างชัดเจน ถ้าตีได้เบา V2 ซึ่งเลี้ยวเร็วกว่าเกือบ 2 เท่าและเข้าใต้ขอบข้าง 4 มม. ของ V4 ได้แทบทุกครั้ง จะชนะด้วยแต้มคุมเกม

## อันดับ

| สมมติฐาน | อันดับ |
|---|---|
| หลัก | **V4 > R3 > V2** |
| มองแง่ร้ายสำหรับ V4 (V4 แบบเดิม wedgelet ยึดตาย ไม่มี skirt) | ชนะวนกันแบบเป่ายิงฉุบ: V2 ชนะ V4, R3 ชนะ V2, V4 สูสีกับ R3 |
| **มองแง่ร้ายสำหรับ V4 (V4 ตอนนี้: skirt + wedgelet บานพับ)** | **V4 > R3 > V2** (V4 ชนะ V2 55%, ชนะ R3 97%) |

ไม่มีชุดสมมติฐานไหนที่ V2 ดีที่สุดโดยรวม

## สิ่งที่ควรแก้ใน V4 (จากผลนี้)

1. **(ทำแล้ว 4 ต.ค. — ดูหัวข้อ V4 + skirt ด้านบน) จุดอ่อนใหญ่ที่สุดคือขอบข้างและขอบท้ายสูง 4 มม.** จำลองแยกเฉพาะ V4 ว่าคู่ต่อสู้มุดใต้ข้างได้กี่ %:

   | ขอบข้าง/ท้ายของ V4 | V2 มุดได้ | R3 มุดได้ |
   |---|---:|---:|
   | ตอนนี้ (4 มม.) | 98% | 100% |
   | skirt ติดตาย 1 มม. | 51% | 42% |
   | **skirt บานพับ ห้อยแตะพื้น** | **24%** | **7%** |

   **แนะนำแบบบานพับแตะพื้น** เพราะแบบติดตาย 1 มม. ยังแพ้ลิ่มของ R3 ที่ต่ำ 0.5–1.5 มม. เกือบครึ่ง ส่วนแบบบานพับยังแพ้ลิ่มข้างของ V2 ที่แตะพื้นอยู่ 24%
   **ต้องเช็กน้ำหนักด้วย:** skirt หนักประมาณ 50–60 กรัม แต่ตอนนี้เหลือเผื่อแค่ 110 กรัม
2. **(ทำแล้ว 4 ต.ค. — ดูหัวข้อ V4 ตามที่สร้างตอนนี้) ทำ wedgelet ให้แตะพื้นจริง** เช่นแบบบานพับ เพื่อให้ขอบต่ำกว่าลิ่มของ R3 (0.5–1.5 มม.) ลดจังหวะที่อีกฝ่ายมุดเข้าใต้ ซึ่งเป็นตัวแปรที่พลิกผลได้มากที่สุด
3. **ทดสอบของจริง:** ให้ใบ V4 ตีลิ่มเหล็กที่ต่ำ 1 มม. ในกล่องปิด แล้ววัดว่าลิ่มกระเด็นสูงแค่ไหน ผลนี้จะบอกว่าสมมติฐานหลักหรือแบบมองแง่ร้ายใกล้ความจริงกว่า

## สมมติฐานทั้งหมด

| ค่า | ช่วงที่ใช้ | ที่มา |
|---|---|---|
| แรงเสียดทานยางกับพื้น μ | 0.4–0.8 ทุกคัน | สมมติ (พื้นพลาสติก/กระเบื้อง) |
| ความคลาดของความสูงขอบ | σ 0.7 มม. | เท่ากับตัวจำลองเดิม |
| ระยะเล็งพลาดตอนชนหน้า | ±60 มม. | สมมติ |
| สัดส่วนพลังงานใบที่ส่งไปคู่ต่อสู้ ชนตรงๆ / อีกฝ่ายมุดใต้แล้ว | 20–40% / 5–20% (หลัก); 10–25% / 1–5% (มองแง่ร้าย) | สมมติ **ค่านี้พลิกผลได้มากที่สุด** |
| ความสูงที่นับว่าตีโดน | 0.3 ม. (หลัก) / 0.6 ม. (มองแง่ร้าย) | สมมติ |
| โอกาสลอยแล้วตกคว่ำ | 30–70% (หลัก) / 10–30% (มองแง่ร้าย) | สมมติ |
| lifter V2 พังเมื่อโดนใบตีตรงใบตัก | 40–80% ต่อครั้ง (เมื่อส่งพลังงานเกิน 10%) | สมมติ อ้างอิงรายงานก้านต่อ V2 ที่บอกว่าแรงเกิน 51 N ดันเฟืองเซอร์โวกลับ; lifter พังแล้ว V2 ยังคุมได้ด้วยลิ่มติดตาย |
| R3 ตอนคว่ำ | มุดใต้อะไรไม่ได้และยกไม่ได้ (ลิ่มลอยพ้นพื้น) | จากรูปทรง R3 |
| จุดศูนย์ถ่วง V4 | อยู่หน้าเพลาเล็กน้อย (y +5 มม.) | สมมติ |
| จำนวนการปะทะต่อแมตช์ / สัดส่วนชนหน้า | 4–10 ครั้ง / 30–70% | สมมติ จึงรายงานเป็นช่วง |
| การตัดสินเมื่อไม่มีใครหมด | แต้มคุมเกม (ใช้แทนกรรมการ) | ยังไม่มีกติกาตัดสินจริง |

## ข้อจำกัด

- ไม่มีฟิสิกส์ 3D ไม่มีการเด้ง การหมุนกลางอากาศ ผนังสนาม หรือหลุม
- ไม่ได้คิดความเสียหายสะสม ความร้อน แบตหมด หรือคนขับพลาด
- ไม่ได้คิดความแข็งแรงของ V4 เอง เช่น แผ่นตั้งยึดใบบนบล็อก TPU, ลูกปืน และแรงสะท้อนกลับจากใบ ซึ่งยังไม่มี FEA
- R3 กับ V2 ไม่ได้ปรับให้ใช้น้ำหนักเต็ม 2 กก. จึงเป็นการเทียบหุ่นที่มีอยู่จริง ไม่ใช่เทียบแบบที่ดีที่สุดในแต่ละแนวคิด

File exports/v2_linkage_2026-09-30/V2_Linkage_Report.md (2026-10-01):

# ก้านต่อเซอร์โว lifter ของ V2 (robot2) — 30 ก.ย. 2026

คำนวณจากรูปทรงใน CAD ตามสคริปต์ที่สร้างชิ้น (`fusion_scripts/Fix123Stage2.py`, `AddWedgeLifterOption.py`) ซึ่งตรงกับไฟล์ `robot2_items_1_3_2026-09-24.f3d`. รอบนี้ไม่ได้เปิด Fusion และ **CAD ยังไม่ถูกแก้**. สร้างผลซ้ำได้ด้วย `python3 v2_linkage.py`.

แบบจำลองเป็น four-bar ในระนาบ y–z: ไม่มีแรงเสียดทาน ไม่คิดระยะคลอนของรูหมุด และใช้แรงบิด stall อุดมคติ 3.92 N·m (40 kgf·cm ที่ 7.4 V). นิยามแรงปลายใช้แบบเดียวกับตาราง V3 R3 จึงเทียบกันได้โดยตรง.

## รูปทรง (แกน robot2: y ไปหน้า, z ขึ้นจากพื้น, หน่วย มม.)

| จุด/ชิ้น | ค่า |
|---|---|
| แกนเซอร์โว S | (42, 22) |
| horn | 15 มม. หมุดปลาย (57, 22) ชี้ไปหน้าในแนวนอนตอนพัก |
| ก้านต่อ | 23.77 มม. จาก (57, 22) ถึง (63, 45) |
| คันโยกบนบอส | 14.40 มม. จากแกน lifter P (68, 31.5) |
| ปลายใบ | (112, 5.8) ห่างแกน 50.96 มม. สูงจากพื้น 5.8 มม. ตอนพัก |

การยกใบ 0 → 45° ต้องหมุนเซอร์โว **33.4°** (horn ปัดลง). Repeat 40 kg หมุนได้ 270° จึงเหลือช่วงหมุนมาก แต่ต้องตั้ง endpoint ของช่องสัญญาณให้ใช้ช่วงเพียง 33° นี้.

## ผล — แรงยกที่เซอร์โวดับ (stall)

| ยก | เซอร์โวหมุน | ปลายสูง | แรงปลาย ⟂ รัศมี | แรงปลาย แนวดิ่ง | แรงในก้านต่อ | มุมส่งแรง* |
|---:|---:|---:|---:|---:|---:|---:|
| 0° | 0° | 5.8 มม. | **43.7 N** | 50.6 N | 270 N | 34.9° |
| 10° | 5.9° | 13.8 | 47.1 | 50.2 | 262 | 39.5° |
| 20° | 12.4° | 22.4 | 52.9 | 53.7 | 264 | 45.2° |
| 30° | 19.7° | 31.2 | 61.3 | 61.3 | 275 | 52.3° |
| 45° | 33.4° | 44.4 | **80.1** | 82.8 | 310 | 66.3° |

\*มุมระหว่างก้านต่อกับคันโยก 90° ดีที่สุด ต่ำกว่า ~40° ถือว่าส่งแรงไม่ดี. ค่าเต็มทุก 0.5° อยู่ใน `v2_linkage_sweep_as_built.csv`.

- **ยกคู่ต่อสู้ได้:** การยกข้างหรือหน้าหุ่นขนาด 1.1–1.5 kg ต้องใช้ประมาณ 5–7.4 N จึงมีแรงเผื่อ ≥ 5.9 เท่าตลอดช่วง.
- **ก้านต่อลดแรงบิด ไม่ได้ขยาย:** แรงบิดที่แกน lifter เท่ากับ 0.57–1.04 เท่าของแรงบิดเซอร์โว (2.2–4.1 N·m). จุดอ่อนที่สุดคือตอนเริ่มยก เพราะมุมส่งแรงเพียง 35°.
- **ระยะห่าง:** ก้านต่อ (x −31.1…−28.1) อยู่ช่วง x เดียวกับหมุด Ø6 และห่างผิวหมุดอย่างน้อย 2.25 มม. ตลอดช่วง. ตรวจเฉพาะคู่นี้ใน 2D; การตรวจ interference ใน Fusion เมื่อ 24 ก.ย. ที่ 0/15/30/45° ไม่พบการชนสำคัญ.
- **แรงในชิ้น (ตอนเซอร์โวดับ):** ก้านต่อ 6061 หนา 3 × กว้าง 6 มม. มีรู Ø3.2 เหลือหน้าตัด 8.4 mm² → 37 MPa ที่ 310 N. สลัก M3 รับแรงเฉือน ≈ 62 MPa. ผ่านสำหรับแรงยก แต่ไม่ผ่านกรณีชน (ดูข้างล่าง).

## ⚠️ ปัญหาสำคัญ: ตอนพัก แรงกดที่ปลายใบวิ่งเข้าเฟืองเซอร์โว

| รายการ | ค่า |
|---|---|
| แรงบิดที่เซอร์โวต้องต้านต่อแรงกดปลาย 100 N ตอนพัก | **7.75 N·m** (≈ 2 เท่าของ stall) |
| แรงกดปลายที่ทำให้เซอร์โวถูกดันกลับ | **≈ 51 N** เท่านั้น |
| แรงชนอ้างอิง 583 N (impact sim V2, 0.5 m/s) ตอนพัก | แรงบิดย้อนเข้าเซอร์โว ≈ 45 N·m (**11 เท่าของ stall**), แรงในก้านต่อ ≈ 3,100 N (หน้าตัดก้านต่อรับได้ ≈ 2,300 N ที่ 275 MPa) |
| ใบลงไปแตะพื้น | ที่ −7.9° (ปลายสูงจากพื้น 5.8 มม. ตอนพัก) |
| ใบลงไปแตะ `Lifter_Lower_Hard_Stop` | ที่ −8.2° — **ช่องว่าง 4.4 มม. ตอนพัก** จึงแตะพื้นก่อน stop |

ตอนพัก horn ทำมุม 75° กับก้านต่อ จึงยังไม่ใช่ท่า toggle. ใบลอยอยู่ได้เพราะเซอร์โวถือไว้ ส่วน hard stop ยังไม่ได้รับแรง. ถ้าถูกกดหรือถูกชนที่ปลายใบ เฟืองเซอร์โว ก้านต่อ และสลักจะรับแรงก่อน จนกว่าใบจะลงไปแตะพื้น. ขณะยกอยู่ก็ถูกดันกลับได้แบบเดียวกัน (4.7–7.9 N·m ต่อแรงกด 100 N) และยังไม่มี stop บนที่ 45° (มีเพียง joint limit ใน Fusion).

## ทางแก้ (ยังไม่ได้แก้ใน CAD)

1. **ยก hard stop ขึ้น ≈ 4.4 มม.** (ผิวบนจาก z 13 → ≈ 17.4 ที่ y 82–89) ให้ใบวางบน stop ตอนพัก 0°. แรงกดตอนพักจะลงโครงแทนเซอร์โว. ให้เซอร์โวดึงใบลงกด stop เล็กน้อย. **ต้องทำข้อนี้ก่อน** เพราะแก้ปัญหาได้โดยไม่ต้องเปลี่ยนก้านต่อ. ต้องตรวจ interference ใน Fusion อีกครั้ง.
2. **เพิ่ม stop บนที่ 45°** บนโครงหรือขารองรับแกน แบบเดียวกับ V3 R3 ที่มี stop 60°.
3. **(ทางเลือก) จัดให้ตอนพักอยู่ท่า toggle แบบ V3:** horn 15 มม. ชี้ไปที่หมุดคันโยกตอนพัก หมุด horn อยู่ที่ (52.1, 33.1) และก้านต่อสั้นลงเหลือ 16.14 มม. ผลคำนวณ: แรงปลาย ≥ 58 N ตลอดช่วง (373 N ที่ 0.5°), มุมส่งแรง ≥ 48.7°, ห่างหมุด ≥ 4.8 มม., เซอร์โวหมุน 49.5°. ตอนพักแรงกดแทบไม่ย้อนเข้าเฟือง แต่จะลงเพลาและลูกปืนของเซอร์โวแทน. ข้อ 1 จึงยังจำเป็น. ข้อนี้ต้องย้ายรู horn และทำก้านต่อใหม่ และยังไม่ได้ตรวจการชนกับบอสใน Fusion.

## สคริปต์แก้ข้อ 1–2 (30 ก.ย.)

`fusion_scripts/V2_Lifter_Stops/` (ในชุด PC: `05_Fusion_Scripts/V2_Lifter_Stops`). **รันใน Fusion แล้ว 1 ต.ค. ผล OK** บนสำเนาที่ไม่บันทึก; ผลเก็บเป็น `exports/robot2_lifter_stops_2026-10-01.f3d`/`.step`. ไฟล์ `robot2` บน cloud ไม่ถูกแก้.

- **stop ล่าง:** ต่อบล็อกเดิม (x −10…10, y 82…89) ให้ผิวบนเอียงตามใต้ใบ z 20.94 → 17.41 ใบวางบน stop เต็มหน้า 7 × 20 มม. ที่ 0°
- **stop บน:** บล็อกใหม่บนขารองรับแกนขวา x 16…32, หน้าตัด y−z (63.5, 36.5)–(66.64, 36.5)–(69.06, 38.93)–(72, 39.5)–(72, 46)–(63.5, 46). ผิวเอียง 45° ตรงกับผิวบนของบอสที่ยก 45° สัมผัสยาว 3.4 มม. × กว้าง 14 มม.
- **ตรวจใน Fusion ตรงกับ 2D:** 0° แตะ stop ล่าง 0.000 มม.; 44° ห่าง stop บน 0.044 มม.; 45° แตะ; ไม่มี interference กับชิ้นที่แสดงอยู่ทั้ง 60 ชิ้น.
- **ตรวจ 2D:** ช่วง 0–44.5° บอส/ใบห่าง stop บน 0.5 → 0.02 มม. และแตะพอดีที่ 45°. ใบแยกจาก stop ล่างทันทีที่ยก (0.3 มม. ที่ 1°)
- **แรงที่ stop บนเมื่อเซอร์โวดันเต็ม:** ≈ 0.9 kN (แรงบิดที่แกน 4.08 N·m, ระยะจากแกนถึงผิวสัมผัส 4.5 มม.). บล็อกยื่นจากขารองรับ 16 มม. จึงควรตั้ง endpoint เซอร์โวให้หยุดก่อน stop (~43–44°) และให้ stop รับเฉพาะแรงเกินหรือแรงชน. ต้องตรวจ FEA/ยึดสกรูจริงก่อนผลิต
- **ตอนพัก:** ตั้ง endpoint ล่างเลย 0° เล็กน้อย (~−1°) ให้เซอร์โวกดใบลงบน stop (≈ 130 N)

## เทียบกับ V3 R3 (นิยามแรงเดียวกัน, เซอร์โวรุ่นเดียวกัน)

| | V2 (ตามที่สร้าง) | V3 R3 |
|---|---:|---:|
| ช่วงยก | 0–45° | 0–60° |
| ปลายสูงสุดจากพื้น | 44.4 มม. | 35.9 มม. |
| แรงปลายตอนเริ่มยก | 43.7 N (0°) | 519 N (1°) |
| แรงปลายต่ำสุดในช่วงยก | 43.7 N | 67 N (60°) |
| ตอนพัก | ไม่ใช่ toggle, เซอร์โวถือใบ, ห่าง stop 4.4 มม. | toggle + แท็บวางบนปีก |
| stop บน | ไม่มี | มี ที่ 60° |

ไฟล์: `v2_linkage.py`, `v2_linkage_results.json`, `v2_linkage_sweep_as_built.csv`, `v2_linkage_sweep_toggle_option.csv`, `v2_linkage.png`.

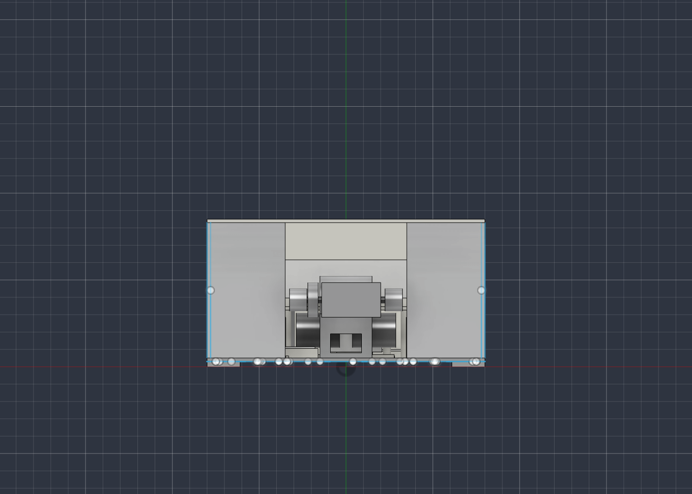
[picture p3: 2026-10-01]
exports/views/robot_beater_concept_attack_side.png

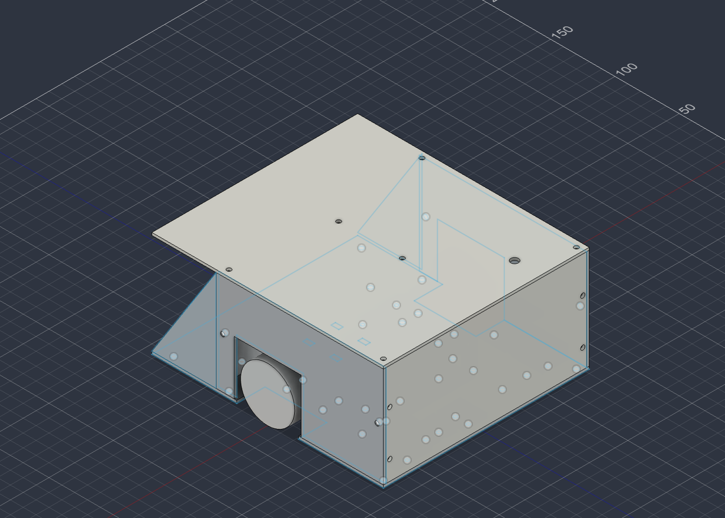
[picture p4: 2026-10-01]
exports/views/robot_beater_concept_attack_iso.png

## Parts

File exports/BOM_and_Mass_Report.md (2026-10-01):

# ESP32 Mini BattleBot — BOM & Mass Report

> **HISTORICAL — do not use for the competition variant.** Read `../STATUS.md`,
> `Mass_Report_Generated.md`, and `Design_Review_Competition_2026-09-23.md`.
> This table predates the switch replacement and removal of the top hammer.
> `BattleBotFixes.py` is a legacy script and must not be run on the current robot2 design.
>
> Two known errors in the figures below are described in `../STATUS.md`:
> the front wedges are modelled as **45 mm solid aluminium** (413 g for the pair,
> almost certainly unintended), and the two analysis envelopes carry ~91 g of
> phantom mass because they were assigned ABS.

Generated from Fusion 360 model `robot` (BattleBot_Master), 2026-09-22.

## Bill of Materials (real parts, Thai retail)

| Subsystem | Part | Spec | Real mass | Price (THB) | Source |
|---|---|---|---:|---:|---|
| Drivetrain | TT Motor 200RPM ×2 | yellow gearmotor | 20g ea. | ~60-90 | user-specified |
| Drivetrain | Wheel 42mm ×2 | TT wheel | 8g ea. | — | user-specified |
| Front Spinner | A2212 1400KV brushless motor | Ø27.5×30mm | 55g | ~155 | SriTu Hobby |
| Front Spinner | 30A BLHeli ESC | ~45×26×8mm | 25g | ~150-400 | generic |
| Top Hammer | DS3218MG 20kg digital servo | 40.5×20×40.5mm | 60g | ~440-690 | SriTu Hobby / ThaiEasyElec |
| Electronics | 3S 2200mAh LiPo | 104×35×27mm | 200g | ~450-700 | FPVONLY (GNB/Gens-Ace class) |
| Electronics | ESP32-C3 SuperMini + control PCB (assembled) | 60×50mm footprint | ~30g | — | plan.md baseline |
| Electronics | RC receiver | — | 8g | — | generic |
| Electronics | Motor driver board | — | 10g | — | generic |
| Electronics | Buck/BEC | — | 8g | — | generic |
| Electronics | Main disconnect switch | — | 10g | — | generic |
| Electronics | Spinner shaft bearings ×2 | 623/624-class | 5g | — | generic |

**All items well within the 1,500-3,000 THB/item budget** — actual unit costs are much lower, leaving headroom to upgrade (e.g. higher-KV motor, premium servo) if desired.

## Mass Report

### CAD-computed mass (fabricated/structural parts — trustworthy, these are being designed not bought)

| Part | Material | Mass |
|---|---|---:|
| Base_Plate_Al | Aluminum 6061 | 155.5 g |
| Left_Side_Plate_Al | Aluminum 6061 | 35.9 g |
| Right_Side_Plate_Al | Aluminum 6061 | 35.9 g |
| Front_Wedge_L | Aluminum 6061 | 206.6 g |
| Front_Wedge_R | Aluminum 6061 | 206.6 g |
| Top_Cover | Nylon 6 | 64.5 g |
| Left/Right_Support (spinner bearing blocks) | Aluminum 6061 | 3.6 g ea. |
| Spinner_Shaft | Steel | 4.0 g |
| Spinner_Bar (weapon) | ~~Aluminum 6061~~ → **Aluminum 7075-T6** (applied by the script, ≈22 g) | 21.1 g |
| Hammer_Arm | Aluminum 6061 | 32.4 g |
| Hammer_Head | Aluminum 6061 | 24.3 g |
| PCB_Standoff ×4 | Nylon 6 | 0.1 g |
| Battery_Holder | Nylon 6 | 8.2 g |
| **Structural subtotal** | | **≈ 802 g** |

*(Excludes `Spinner_Sweep_Envelope` and `PCB_Keepout_Envelope` — these are reference/analysis volumes, not real parts, and are not counted toward mass.)*

### Corrected total (structural CAD mass + real BOM masses, not the inaccurate solid-envelope mass of purchased parts)

| Category | Mass |
|---|---:|
| Structural/fabricated (CAD, aluminum+nylon+steel) | 802 g |
| Purchased components (real datasheet masses, see BOM) | 477 g |
| Fasteners & wiring allowance | 100 g |
| Design-change margin | 90 g |
| **Total estimated mass** | **≈ 1,469 g** |

**Target: 1,500 g — currently ≈31g under budget.** Center of mass: x=0 (centered), y=+11mm (slightly forward), z=33mm above ground (low and stable).

## Known simplifications / follow-ups
- Spinner drive is belt/pulley in concept — pulleys and belt not modeled, only
  clearance-checked. **The drive ratio is therefore still undefined, so the
  ~10 J weapon-energy figure (which assumes 1:1) is not yet a usable number.**
- Bearing/shaft mismatch: `spinner_bearing_OD` 13 mm is a 624 (4 mm bore) but
  `spinner_shaft_D` is 3.17 mm (1/8"). Pick 623 + 3 mm shaft, R2-5 + 1/8" shaft,
  or step the shaft up to 4 mm and keep the 624.
- PCB standoffs pass through the PCB body (no drilled through-hole modeled) — cosmetic only.
- Motor/servo mounting bolt patterns not modeled — confirm against actual supplier datasheet before drilling.
- Spinner motor now has a saddle cradle (`Spinner_Motor_Cradle`) bolting it to the
  base plate with 4× M3 — pending the script run.
- Wire_Clips, Non_Structural_Covers, TPU_Bumpers left as empty placeholder components — need real cable routing / impact-zone info.

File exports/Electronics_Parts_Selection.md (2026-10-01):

# เลือกชิ้นส่วนอิเล็กทรอนิกส์จริง — แทนกล่องสมมติ 25×20×10 mm

> อัปเดต 2026-09-23: รุ่นแข่ง `robot2` ใช้ตัวแทนรูปทรง
> `FingerTech_Mini_Switch_Envelope` และ `FingerTech_Switch_Adapter` แล้ว;
> ชุดค้อนบนถูกถอดออก. ตารางและข้อเสนอเดิมด้านล่างเป็นประวัติการเลือกอะไหล่
> ไม่ใช่แบบผลิตขั้นสุดท้าย. ขั้วสวิตช์/ทางเดินสาย, แบต, ESP32 และชุดขับ
> ยังต้องเทียบกับชิ้นจริง. อ่าน `Design_Review_Competition_2026-09-23.md` ก่อนสั่งอะไหล่.

ค้นเมื่อ 2026-09-23 ราคาเป็น USD ตามหน้าผู้ผลิต แปลงเป็นบาทคร่าว ๆ ที่ ~34 ฿/USD **ยังไม่รวมค่าส่ง**

## รายการที่เลือก

| หน้าที่ | รุ่น | ขนาด (mm) | น้ำหนัก | รูยึด | ราคา | ซื้อที่ |
|---|---|---|---:|---|---:|---|
| ตัวรับสัญญาณ | **RadioMaster ER6** (ELRS 2.4 GHz, PWM 6 ช่อง) | 43 × 25 × 15 | 14.5 g | **ไม่มี** | $24.99 (~850 ฿) | ไทย: UDSHOBBY |
| ไดรเวอร์มอเตอร์ล้อ | **Pololu DRV8874** carrier × 2 | 15.2 × 17.8 (0.6 × 0.7″) ต่อตัว | ~0.9 g | **ไม่มี** — ขา header 0.1″ | $11.94/ตัว (~810 ฿ คู่) | Pololu / RobotShop |
| ESC อาวุธ | **Holybro Tekko32 F4 45A (AM32)** | 17.3 × 34.3 × 4.5 | 5.8 g | **ไม่มี** | $23.99 (~820 ฿) | Holybro |
| BEC | **Hobbywing UBEC 5A V2 Air** | 50 × 17 × 10 | 21 g | **ไม่มี** | ~550 ฿ | ไทย: Lazada |
| สวิตช์ตัดไฟหลัก | **FingerTech Mini Power Switch (Metric)** | 12.7 × 12.7 × 6.35 + ขั้วยื่น 6.35 | 2.15 g | **2 รู ห่าง 7.62 mm** ใส่ M2 ทะลุ หรือต๊าป M3 | $8.66 (~300 ฿) | FingerTech / RobotShop |

**รวมชิ้นส่วน ≈ 3,330 ฿** ไม่รวมค่าส่ง และ**ไม่รวมรีโมท**

ต้องมีรีโมท ELRS ด้วย ถ้ายังไม่มี: RadioMaster Pocket (ELRS) ราคา 2,600 ฿ ที่ FPVTHAI
(ตอนเช็ก รุ่น ELRS บางสีของหมด) → รวมทั้งชุด ≈ 5,930 ฿

น้ำหนักรวม 45.3 g — เบากว่าที่ BOM เดิมประมาณไว้ (61 g) ประมาณ 16 g

## เหตุผลที่เลือก

**ER6** — ค่า failsafe ที่บันทึกไว้ก่อนหน้าอ้างช่อง 3 = 988 µs และช่องอื่น = 1500 µs.
**อย่าถือว่าใบมีดจะหยุดเองโดยไม่ทดสอบ**: ต้องตั้งค่า failsafe บนตัวรับ/รีโมทจริง,
ตรวจทิศทาง ESC แล้วทดสอบการปิดรีโมทและสัญญาณขาดในสภาพที่ล็อกอาวุธอยู่.

**DRV8874 แทน TB6612FNG** — TB6612 ทนแรงดันสูงสุด 13.5 V แต่แบต 3S ตอนเต็มคือ 12.6 V
เหลือ margin แค่ 0.9 V และจ่ายต่อเนื่องได้แค่ 1 A/ช่อง ส่วน DRV8874 ทน 4.5–37 V
จ่ายต่อเนื่อง 2.1 A มีกันขั้วกลับ และจำกัดกระแสในตัว

**Tekko32 F4 45A (AM32)** — เลือกเป็นตัวเลือก ESC สำหรับ A2212 แต่กระแสและ
การรับสัญญาณต้องตรวจจากรุ่นที่ซื้อและทดสอบพร้อมมอเตอร์/ใบมีดจริง.

ตัวเลือกที่ออกแบบมาเพื่อหุ่นยนต์ต่อสู้โดยตรง เช่น RevvitRC 50A ($42) มี BEC ในตัว
แต่ BEC ของมันออก 7.4/8.4 V **เกินกว่าที่ servo DS3218MG รับได้ (สูงสุด 6.8 V)** จึงไม่เลือก

**UBEC 5A** — servo DS3218MG กินกระแสตอนค้างได้หลายแอมป์ 5 A ต่อเนื่อง / 15 A ชั่วขณะ
เผื่อพอ ตั้งเอาต์พุตไว้ **6.0 V** เลี้ยง servo กับตัวรับ

**FingerTech** — มาตรฐานวงการหุ่นยนต์ต่อสู้ รับ 40 A ต่อเนื่อง / 100 A 10 วินาที
**เปิด-ปิดด้วยประแจหกเหลี่ยม 2.5 mm จากนอกตัวหุ่น**

## ESP32 — บอร์ดที่เลือก (2026-09-23)

**ESP32 DevKit 30 ขา (ESP32-WROOM-32, CH9102X, micro-USB, รูยึด 4 มุม)** ตามรูปที่ผู้ใช้ส่งมา (Arduitronics)

| | ค่า | ที่มา |
|---|---|---|
| ขนาดบอร์ด | 51.5 × 28.3 mm (ผู้ขายระบุ 51.8 × 28.2) | วัดจากรูป + ผู้ขาย |
| ระยะรูยึด ศูนย์-ศูนย์ | **47.2 × 23.4 mm** | **วัดจากรูป ±0.5 mm — ต้องวัดตัวจริงด้วยเวอร์เนียก่อนพิมพ์** |
| ขนาดรู | ≈ Ø2.5–3 → ใช้สกรู **M2** | วัดจากรูป |
| แถว header | ห่าง 25.4 mm, 15 ขา/แถว, ขาชี้ลง | วัดจากรูป |

ในโมเดล: บอร์ดวางบน **`Holder_ESP32`** (แผ่นรองพิมพ์ 3D + เสา Ø4.5 สูง 18 mm × 4)
ใต้บอร์ดเว้น 18 mm ให้หัว DuPont เสียบขาที่ชี้ลง แผ่นรองขันลงแผ่นฐานด้วย M3 2 ตัวที่ (±15, −38)
**รูของ ESP32 อยู่ในชิ้นพิมพ์ ไม่ได้เจาะลงอลูมิเนียม** — ถ้าวัดตัวจริงแล้วไม่ตรง แค่พิมพ์แผ่นรองใหม่

## ✅ ทำในโมเดลแล้ว (2026-09-23)

กล่องสมมติ, รู M2 บนแผ่นฐาน, เสา T ของ ESC และฝาครอบบอร์ดเดิมถูกลบออก
ใส่ชิ้นส่วนขนาดจริงพร้อม **holder พิมพ์ 3D** (Nylon/PETG) แทน

| ชิ้นส่วน | ตำแหน่ง (x, y) | holder (mm) | มวล holder | รู M3 บนแผ่นฐาน |
|---|---|---|---:|---|
| ESC Tekko32 | (35, 28) ข้างมอเตอร์สปินเนอร์ | 37.9 × 20.9 × 5.5 | 2.3 g | (21.9, 28), (48.1, 28) |
| RadioMaster ER6 | (−52, −63) หลังซ้าย | 28.6 × 46.6 × 16.0 | 6.4 g | (−52, −80.5), (−52, −45.5) |
| UBEC 5A | (66, −51) ขวา ใกล้แบต | 20.6 × 53.6 × 11.0 | 4.6 g | (66, −72), (66, −30) |
| DRV8874 A | (−26, −74) หลังกลาง | 21.4 × 18.8 × 4.0 | 1.0 g | (−31, −74), (−21, −74) |
| DRV8874 B | (−4, −75) ข้าง A | 18.8 × 21.4 × 4.0 | 1.0 g | (−4, −80), (−4, −70) |

**แบบ holder:** ร่องเผื่อข้างละ 0.2 mm, ผนัง 1.6 mm สูงน้อยกว่าชิ้นส่วน 1 mm,
พื้นหนา 2 mm, ร่องใต้ฐานกว้าง 4 mm ลึก 1.2 mm สำหรับเคเบิลไทร์

**ลำดับประกอบ:** ขัน holder ลงแผ่นฐานก่อน (M3 หัวเรียบ 2 ตัว ผ่านพื้น holder ลงรูเกลียวในแผ่นฐาน)
→ แปะเทปโฟมที่พื้นร่อง → วางชิ้นส่วน → รัดเคเบิลไทร์รอบชิ้นส่วน + holder ผ่านร่องใต้ฐาน

> M3 ในอลูมิเนียมหนา 2 mm กินเกลียวแค่ ~4 รอบ พอสำหรับชิ้นเบา ๆ เหล่านี้
> ถ้าคลายบ่อยให้เปลี่ยนเป็น rivnut

DRV8874 ที่ถูกต้องจริง ๆ ควรอยู่บน PCB ควบคุม — holder นี้เป็นทางออกระหว่างที่ยังไม่มี PCB

## สิ่งที่ต้องแก้ในโมเดล (บันทึกเดิมก่อนการแก้ล่าสุด; บางข้อทำแล้ว)

**1. ส่วนใหญ่ไม่มีรูยึด** — มีแค่สวิตช์ FingerTech ที่มีรู ที่เหลือยึดด้วยเทปโฟมกาวสองหน้า
เวลโคร หรือเคเบิลไทร์ แปลว่า:

- รู M2 บนแผ่นฐานใต้ RC receiver, driver, BEC **ผิดตั้งแต่หลักการ** ควรเปลี่ยนเป็นพื้นเรียบ
  สำหรับแปะเทป หรือช่องร้อยเคเบิลไทร์
- ฝาครอบบอร์ด `Shield_*` เดิมนั่งบนสกรู M2 ของบอร์ด ต้องออกแบบวิธียึดใหม่
- เสา T ของ ESC ออกแบบไว้สำหรับกล่องสมมติ 45 × 26 ที่มีรู แต่ Tekko32 ขนาด 17.3 × 34.3
  และไม่มีรู — ไม่ต้องใช้เสาแล้ว

**2. ไดรเวอร์มอเตอร์ต้องอยู่บน PCB ควบคุม** — DRV8874 เป็นบอร์ดเสียบขา ไม่ใช่โมดูลแยก
ลบกล่อง `Wheel_Motor_Drivers` ออก แล้วเผื่อพื้นที่ 2 × (15.2 × 17.8) mm บน PCB ESP32 แทน

**3. สวิตช์ตัดไฟ (ข้อเสนอเดิม; แก้แล้ว)** — รุ่นแข่งใช้ตัวแทน FingerTech
12.7 mm บน adapter ที่ยึดเสาเดิม เพื่อไม่ต้องเจาะฐานใหม่. ปิดช่องฝา
20 × 16 mm แล้วทำรูเข้าประแจ Ø6 mm ที่ตรงศูนย์สวิตช์. ยังต้องตรวจ
ขั้วทองแดงและสายจริง รวมถึงประแจยาวที่เอื้อมถึง.

**4. เสาอากาศ ER6** — สายเสาอากาศยาว 20 cm สองเส้น ต้องออกทางชิ้นที่ไม่ใช่โลหะ
(ฝาบนกับแผงหลังเป็น Nylon — ใช้ได้) อย่าให้อยู่ในกล่องอลูมิเนียม

## ข้อควรระวังทางไฟฟ้า

**มอเตอร์ TT บนแบต 3S** — มอเตอร์ TT รุ่นตัวอย่างใช้แรงดันพิกัด 3–6 V แต่แบต 3S
เต็มราว 12.6 V. การจำกัด PWM ราว 50% **ไม่ใช่การยืนยันความทน** ของมอเตอร์และเกียร์
ในการชน; รุ่นแข่งควรเลือกมอเตอร์เกียร์โลหะที่เหมาะกับไฟเลี้ยง/ไดรเวอร์แล้วแก้ CAD.
ดู [สเปก TT ตัวอย่างจาก Adafruit](https://www.adafruit.com/product/3777).

**ไฟเลี้ยง ESP32** — ข้อความเดิมที่สรุปว่า “ป้อน 6 V เข้า VIN ได้เลย” ยังไม่ได้
ยืนยันจากบอร์ดที่ซื้อจริงหรือทดสอบความร้อนของ regulator. ตรวจสเปกบอร์ดและ
วัดแรงดัน/อุณหภูมิภายใต้โหลดก่อนต่อไฟใช้งานจริง.

**สายสัญญาณ ESC อาวุธ** — แนะนำให้ต่อ **จาก ER6 ช่อง 3 เข้า ESC ตรง ๆ ไม่ผ่าน ESP32**
ถ้า ESP32 ค้างขณะสั่งอาวุธหมุน ใบมีดจะไม่หยุดเอง แต่ถ้าต่อตรงจากตัวรับ failsafe ของตัวรับ
จะตัดอาวุธได้เสมอ ส่วนล้อให้ ESP32 อ่านช่องจากตัวรับแล้วสั่ง DRV8874

## แหล่งข้อมูล

- [RadioMaster ER6 — ผู้ผลิต](https://radiomasterrc.com/products/er6-2-4ghz-elrs-pwm-receiver)
- [ExpressLRS PWM receivers — failsafe](https://www.expresslrs.org/hardware/pwm-receivers/)
- [RadioMaster ER6 — UDSHOBBY (ไทย)](http://www.udshobby.com/product/1937/radiomaster-er6-2-4ghz-elrs-pwm-6ch-receiver)
- [RadioMaster Pocket ELRS — FPVTHAI](https://www.fpvthai.com/products/%E0%B8%A7%E0%B8%B4%E0%B8%97%E0%B8%A2%E0%B8%B8%E0%B8%9A%E0%B8%B1%E0%B8%87%E0%B8%84%E0%B8%B1%E0%B8%9A-%E0%B8%A3%E0%B8%B5%E0%B9%82%E0%B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)
- [Pololu DRV8874](https://www.pololu.com/product/4035)
- [Pololu TB6612FNG + แบบมิติ](https://www.pololu.com/product-info-merged/713)
- [Holybro Tekko32 F4 45A AM32](https://holybro.com/products/tekko32-f4-45a-esc)
- [RevvitRC 50A AM32 (ไม่เลือก)](https://itgresa.com/product/just-cuz-robotics-revvitrc-50a-am32-esc-with-bec/)
- [Hobbywing UBEC 5A](https://www.hobbywing.com/en/products/ubec-5a93)
- [FingerTech Mini Power Switch Metric](https://www.fingertechrobotics.com/proddetail.php?prod=ft-mini-switch-metric)

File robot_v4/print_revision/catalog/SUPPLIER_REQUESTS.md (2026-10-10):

# ชุดขอข้อมูลและใบเสนอราคา — Robot V4 Print R2

ข้อความด้านล่างเตรียมให้ผู้ใช้ส่งเอง ยังไม่ได้ติดต่อร้าน ไม่ได้จองของ และไม่ได้อนุมัติผลิต ใช้คู่กับ [PROCUREMENT.md](PROCUREMENT.md), ASSEMBLY.md, MACHINING.md และ SHOP_HANDOFF.md

## มอเตอร์ขับ — FromFactory / Mechashop DCM068

> ขอข้อมูล JGA25-370 12V 400rpm รหัส DCM068 จำนวน 4 ตัวรุ่นและล็อตเดียวกันครับ ขอราคา/ค่าส่ง/จำนวนพร้อมส่งจริง และรูปฉลากกับ drawing จากสินค้าที่จะส่ง รวมความยาวตัวมอเตอร์และเกียร์, Øตัว, Øและความสูงบ่าหน้า, Øเพลา, ความยาวเพลาที่ยื่นจากหน้าเกียร์, ความลึก/ความยาวด้านแบน, พิกัดรูยึดจากศูนย์เพลา, ขนาดเกลียวและความลึกขันปลอดภัย, น้ำหนักรวมสาย และกระแส no-load/rated/stall ที่12V ขอภาพคาลิปเปอร์ที่วัดจุดสำคัญด้วยครับ ข้อมูลนี้ใช้ทำรูและดุม CAD ก่อนพิมพ์ ไม่สามารถใช้ drawing รุ่นรอบอื่นแทนโดยไม่มีการยืนยันได้

หน้า Mechashop แสดง 2 ตัวในผลค้น แต่ต้องใช้ 4 ตัว; FromFactory ระบุพร้อมส่งแต่ไม่แสดงจำนวน ห้ามรวมเป็น 4 ตัวจากสองเว็บจนกว่าร้านจะยืนยันว่าเป็นสินค้ารุ่นเดียวกันและมีจำนวนจริง

## มอเตอร์อาวุธ — รุ่นหลักและทางเลือก

> ต้องการมอเตอร์ DYS D3536 1250KV ที่มีสินค้าส่งจากไทย 1 ตัว ขอชื่อ SKU/short หรือ long shaft, รูปฉลาก/สินค้าจริง, ราคาและค่าส่ง พร้อม drawing: ความยาวตัว/Øตัว, น้ำหนักรวมสายและขั้ว, Øเพลา/ส่วนที่ยื่น, Øบ่า, ตำแหน่งและเกลียวรูยึด/ความลึกขันไม่ชนส่วนหมุน, พิกัดกระแสและ ESC ที่แนะนำบน3Sครับ กรุณาแจ้งว่าอุปกรณ์ในชุดมีอะไรบ้าง ไม่ต้องรวมใบพัด

ข้อความสำหรับ UDSHOBBY ทางเลือกแยก:

> ขอข้อมูล SURPASS C3536 V2 1300KV รหัส SKU-02372 โดยระบุ1300KVโดยเฉพาะครับ หน้าเว็บรวม1500KVด้วย ขอ stock/ราคา variant, drawingและมวลรวมสาย/ขั้ว, Øเพลา/ความยาวส่วนยื่น/รูยึด/ความลึกเกลียว, พิกัดกระแสและESCบน3S รวมรูปฉลากV2ของตัวที่จะส่งครับ จะใช้ตรวจความเข้ากันกับCADและรอกก่อนตัดสินใจเปลี่ยนรุ่น

ตัวเลือกนี้ยังไม่ถูกใช้ใน CAD: ต้องประเมินรอบ ความต้องการกระแส รอก และต้นทุนใหม่ก่อนแทน DYS ไม่ใช้ราคาหน้ารวมเป็นใบเสนอราคา

## แบต — FPVONLY SKU-08923

> ขอ DOGCOM3S850mAh150C UCELL XT30 ตัวเลือก3-6.DC850-150C3S UC รหัสSKU-08923 จำนวน1ก้อนครับ ข้อมูลเว็บราคา490บาท/คงเหลือ9 ขอราคาและstockปัจจุบัน พร้อมรูปฉลาก3S11.1V850mAhและขั้วXT30ของสินค้าที่จะส่ง ขอขนาดตัวแบต XYZ ไม่รวมสาย น้ำหนักรวมสาย/ปลั๊ก ความยาวสาย ตำแหน่งออกสายกำลังและbalanceplug รวมขนาดปลั๊กและระยะโค้งสายขณะประกอบครับ รายละเอียด560mAh2Sในหน้าเว็บรวมไม่ใช่รุ่นที่จะใช้

ไม่ใช้ค่ามวลกล่องส่งสินค้า หรือขนาด4S/6S850mAh แทนตัวเลือก3S; ยังต้องวัดก้อนที่ได้รับก่อนปล่อยผลิต

## บอร์ดขับ — ModuleMore SKU01477

> ขอDRV8871 SKU01477 จำนวน2บอร์ดครับ ขอขนาดPCBและความสูงรวมterminal/ขาที่บัดกรี รูยึดถ้ามี น้ำหนักรวมterminal ค่าRlimหรือกระแสlimitที่ตั้งจากโรงงาน กระแสต่อเนื่องและเงื่อนไขระบายความร้อน พร้อมภาพบอร์ดทั้งสองด้านครับ จะต่อมอเตอร์DCM068สองตัวขนานต่อบอร์ด จึงต้องตรวจstall/current-limitก่อนยืนยัน ขนาดIC4.9×6mmใช้แทนขนาดPCBไม่ได้

## สกรู/insert/สายและชิ้นประกบ

ขอราคาตาม BOM ใน ASSEMBLY.md โดยแยกขนาด/ความยาว/ชนิดหัวทุกแถวและรวมแหวน/น็อตล็อก; insert Friend Robot M3×4×5 ใช้14ตัวซื้อ2ถุง10ตัว ถามขนาด OD/ความยาวจริงก่อนเลือก coupon ที่ทดลอง

M8×80 ต้องเป็นหัวหกเหลี่ยมเกรด12.9 ตามแบบ ขอแบ่งขาย1ตัว พร้อมขนาดหัว/ความยาวส่วนเกลียวและแหวน/น็อตล็อกจริง ไม่แทนหัวจมหรือเกลียวตลอดโดยไม่ได้ตรวจ stack

XT30ต้องแยกตัวผู้/ตัวเมียและขนาดสาย16AWG ไม่ใช้ราคาตัวเลือกXT60/14AWG สายรัดต้องกว้างไม่เกิน10mmและยาวรัดก้อน850จริงได้ ขอฟิวส์/holderและขนาดlinkสำหรับcollarด้วย

## งานกลึง/ตัดโลหะ

> ขอราคาเพื่อประเมิน RobotV4PrintR2 ยังไม่สั่งผลิตครับ แนบชุดDRAFT_REVIEWและMACHINING.md ขอราคาแยกวัสดุ/จำนวนตามmanifest: แผ่นโลหะ9แบบ, ดุมโรเตอร์/รอกมอเตอร์/spacers, แกนบานพับØ3×57สองแกนพร้อมร่องEclip, skidUHMW3mm รวมcountersink ต๊าป เก็บคม และงานสวมลูกปืนที่ระบุ ขอระบุtoleranceที่ทำได้และค่าเสียหากแก้รูมอเตอร์หลังวัดของจริง ทุกชิ้นต้องใช้revisionเดียวกัน ยังมีรูยึดมอเตอร์และเพลารอdrawing ไม่ผลิตตำแหน่งเหล่านี้จากnominalครับ

## ร้านพิมพ์

> ขอใบเสนอราคาชิ้นทดลองและชุดเต็มจากRobotV4PrintR2ครับ ยังไม่สั่งพิมพ์ตัวถัง แนบTRIAL_ONLYและDRAFT_REVIEWพร้อมSHOP_HANDOFF.md กรุณาระบุเครื่อง/พื้นที่พิมพ์ใช้ได้จริงXYZ/หัวฉีด/วัสดุTPU95AและPETG/slicerและprofile พร้อมราคาsupport เก็บงาน และส่ง แยกสองช่วง ขอส่งไฟล์โครงการslicerและน้ำหนักต่อชิ้นตามmanifest โดยแยกsupportออกจากชิ้นอยู่บนรถ ตัวถังต้องพิมพ์ชิ้นเดียวประมาณ190.5×217.3×54mmก่อนbrim ขอทดลองDshaft/แกนบานพับ/insert ดุม+ยางหนึ่งชุด บานพับcarrierหนึ่งข้าง และจุดยึดฝา ตามFIT_TEST.md ก่อนครับ

หากร้านต้องการค่ารูที่ยืนยันสำหรับชิ้นทดลอง ให้ล็อก SKU/วัดอะไหล่ก่อนสร้างชุดทดลอง build ใหม่ ไม่แก้ scale/รูใน slicer เพื่อปิดงานโดยไม่แก้ต้นฉบับ

## แบบตอบกลับสั้น

| รายการที่ต้องเก็บ | คำตอบ / แนบหลักฐาน |
|---|---|
| ร้าน / SKU / variant / จำนวนพร้อมส่ง / วันตรวจ | รอยืนยัน |
| ราคาแยกหน่วยขาย + VAT + ส่ง / ระยะเวลาราคามีผล | รอยืนยัน |
| Drawing/รูปคาลิปเปอร์/ฉลากสินค้าที่จะส่ง | รอยืนยัน |
| มวลรวมสาย/ปลั๊ก / ขนาดตัว / พื้นที่สายและเครื่องมือ | รอยืนยัน |
| ข้อมูลไฟ/กระแส/รุ่นต่อเข้ากัน | รอยืนยัน |
| งานพิมพ์:เครื่อง/วัสดุ/profile/brim/support/slicerproject | รอยืนยัน |
| งานโลหะ:วัสดุ/tolerance/รูต๊าป/countersink/เก็บผิว | รอยืนยัน |

บันทึกคำตอบเว็บ/ร้านเป็น catalog หรือ quote เท่านั้น ส่วน actual ต้องได้จากอะไหล่ที่ได้รับจริง และผลfit/assemblyต้องผูกกับ SHA256 ของ build ที่พิมพ์ ไม่กรอก verified=true เพื่อข้ามขั้นตอน

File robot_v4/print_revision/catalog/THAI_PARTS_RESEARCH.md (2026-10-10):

# ข้อมูลอะไหล่ร้านไทย — 8 ต.ค. 2026

**สถานะ: คัดเลือกบางรายการและปรับ R2 ได้แล้ว ยังไม่ใช่ใบสั่งซื้อหรือชุดพร้อมผลิต**

อัปเดตรอบต่อเนื่อง: แยกแบต SKU-08923 ราคา490บาท/เว็บคงเหลือ9ได้แล้ว; [รายการซื้อและงบ](PROCUREMENT.md) กับ [ข้อความขอข้อมูล/ราคา](SUPPLIER_REQUESTS.md) เตรียมครบ แต่ยังไม่มีข้อมูลขนาดใหม่ที่เพียงพอให้แก้ CAD R2 เพิ่ม

ค้นครอบคลุมกลุ่มอะไหล่ในแบบทั้ง27รายการ ไม่ได้อ้างว่าค้นทุกเว็บไซต์ในประเทศไทย ราคาเป็นหน้าเว็บที่อ่านได้ ไม่ใช่ใบเสนอราคา/สต็อกที่ร้านยืนยัน ไม่รวมส่ง/VATที่ยังไม่ชัดเจน

| ID | รุ่น / ร้าน | ราคาที่พบ | สถานะและข้อมูลที่ยังขาด |
|---|---|---:|---|
| TH01 | [JGA25-370 12V 400 rpm / DCM068 / FromFactory](https://www.fromfactory.net/product/6096/ดีซีมอเตอร์-พร้อมเกียร์ทด-jga25-370-gear-dc-motor-12v-high-torque-5-10-30-60-400-rpm-ขนาด-25mm) | 190 บาท | หน้าเว็บระบุพร้อมส่ง; ภาพร้านเป็น D shaft แต่ไม่มี scale/drawing; ไม่อนุมานรูยึด ระยะบ่า ความยาวเพลา หรือ stall current จากรูป รุ่นอื่นชื่อเดียวกันใช้แทนหลักฐานไม่ได้ |
| TH02 | [DYS D3536 1250KV / Angel RC Store (Shopee Thailand)](https://shopee.co.th/dys-d-3536-910-kv-1000-kv-1250-kv-1450-kv-มอเตอร์-brushless-outrunner-สําหรับเฮลิคอปเตอร์เครื่องบินของเล่น-i.53028894.3155547070) | 564 บาท | ผลค้นระบุส่งจากต่างประเทศ; พบหน้าตลาดไทย แต่ยังไม่ใช่ยืนยันของอยู่ในไทย ไม่เลือกเป็นรายการพร้อมซื้อ ต้องขอร้านไทยยืนยันรุ่น 1250KV short/long shaft และ drawing |
| REF02 | [DYS D3536 Long shaft / DYS ผู้ผลิต](https://www.dys.hk/product/D3536%20Long%20shaft.html) | รอ | ต้องยืนยัน; ผู้ผลิตมี variant long shaft; ไม่ถ่ายขนาดเพลา/รูยึดของ variant นี้เข้ามอเตอร์ที่ยังไม่ระบุ SKU |
| TH03 | [Hobbywing Skywalker 40A V2 UBEC / PN80060140 / ABC Flying](https://www.abcflying.com/product/8569/hobbywing-skywalker-40a-v2-ubec-3s-4s) | 490 บาท | หน้าเว็บเปิดสั่งซื้อ; ต้องยืนยันสต็อก; ร้านระบุ 3–4S, BEC5V5A, 14AWG input100mm / output75mm; น้ำหนักและตัวกล่องยังไม่ใช่ measurement หน้างาน ขนาดไม่รวมพื้นที่โค้งสาย |
| ALT03 | [HBW Skywalker 40A / Sky-ESC40A / SrRcTech](https://www.srrctech.com/product/200/hbw-skywalker-esc-40a) | 350 บาท | หมวดสินค้ามีปุ่มสั่งซื้อ; ยังไม่ยืนยันสต็อก; คนละ listing กับ V2; ไม่ใช้ราคา350บาทคู่กับ CAD ขนาด68mm ของ V2 |
| TH04 | [ESP32 30Pin Type-C CH340C ESP-WROOM-32 / 2990 / Mikroelec](https://www.mikroelec.com/product/2990/esp32-30pin-type-c-ch340c-esp-wroom-32-board) | 180 บาท | ต้องยืนยันสต็อก; ขนาดร้านระบุประมาณ; ความสูง14mm และพื้นที่สายเป็น nominal เดิม รอวัดหลังบัดกรีขา |
| TH05 | [DRV8871 DC H-bridge / SKU01477 / ModuleMore](https://www.modulemore.com/product/1477/บอร์ดขับมอเตอร์-drv8871-3-6a-motor-driver-dc-h-bridge-pwm-driver-module) | 75 บาท | หน้าเว็บไม่แสดงจำนวนคงเหลือ; ราคาแสดง75บาทและราคาปกติ99; 4.9×6mm คือ package IC ไม่ใช่ขนาด PCB! คง envelope20×20×6mmแบบเดิม รอขนาดบอร์ด ขั้ว terminal และ Rlim จริง; 3.6A เป็น peak ไม่ใช่ continuous |
| REF05 | [DRV8871 / Texas Instruments](https://www.ti.com/lit/ds/symlink/drv8871.pdf) | รอ | ต้องยืนยัน; ตรวจ current-limit/thermal กับมอเตอร์2ตัวต่อบอร์ดหลังได้รุ่นมอเตอร์จริง ยังไม่รับรอง continuous current |
| TH06 | [GY-521 MPU6050 / M0023 / Cybertice](https://www.cybertice.com/product/40/gy-521-mpu6050-6-axis-imu-module-โมดูลวัดความเร่งและไจโรสโคป-3-แกน) | 80 บาท | หน้าเว็บระบุพร้อมส่ง; ร้านระบุประมาณ21×16mm ไม่ระบุความสูงหลังบัดกรีและน้ำหนัก คงnominalเดิม |
| ALT07 | [GNB6503S160AHV 3S LiHV 650mAh 160C XT30 / FPVTHAI](https://www.fpvthai.com/products/gaoneng-gnb-lihv-3s-11-4v-650mah-160c-xt30-lipo-battery) | 400 บาท | หน้าเว็บมี Add to cart; ชื่อหลักขัดกับรายละเอียด; ชื่อหลักเป็น4S11.4V แต่รายละเอียดเป็น3S1P รอยืนยัน SKU; ลดcapacityจาก850เหลือ650 ต้องทดสอบเวลารันและCG ไม่ใช้แทนเงียบๆ |
| ALT08 | [GNB3S720mAh LiHV100C XT30 / FPVTHAI](https://www.fpvthai.com/collections/battery/products/gnb-3s-720mah-11-4v-100c-xt30-lipo-lihv-battery) | 420 บาท | หน้าเว็บมี Add to cart; ขนาดประมาณ; ไม่มีน้ำหนักที่ยืนยัน ไม่ใช้ลดมวลในCAD |
| ALT09 | [BETAFPV3S850mAh / FPVTHAI](https://www.fpvthai.com/products/betafpv-3s-850-mah-battery) | 750 บาท | Sold out; ไม่ใช้เป็นรายการซื้อปัจจุบัน |
| TH07 | [DOGCOM3S850150C UCELL XT30 / SKU-08923 / FPVONLY](https://www.fpvonly.com/product/dogcom-3s-450-550-560-650-850-1050mah-150c-lipo-battery-อุปกรณ์โดรน-drone/11000371400006958/8923) | 490 บาท | แยกProductGroup.hasVariantและproduct.subproductsจากHTML: ตัวเลือก3-6.DC850-150C3S UC ราคา490ตรงกัน remain9 (เว็บ ไม่ใช่ร้านยืนยัน); หลักฐานevidence/fpvonly_battery_8503s.json; รายละเอียดรวม560mAh2Sใช้ไม่ได้กับ8503S ยังไม่มีขนาด/มวลตรงรุ่น คงnominal75×35×25/80gในCAD |
| TH08 | [SRT25B608ZZ ABEC1 / JISClass0 / Sunrise](https://sunrise.co.th/en/product/deep-groove-ball-bearings-8x22x7-abec-1-jis-b1514-class-0) | 9 บาท | หมวดสินค้าแสดงMax520; ต้องยืนยัน; ใช้2ตลับ ขนาดตรง608เดิม น้ำหนักไม่ระบุและยังไม่รับรองโหลดกระแทก |
| TH09 | [M3×4×5 heat-set insert / 385 (10pcs) / Friend Robot](https://www.friendrobotshop.com/product/385/m3x4x5-insert-nut-สำหรับงานพิมพ์-3d-สำหรับน๊อต-m3-สูง-4-มม-ขนาดเส้นผ่านศูนย์กลาง-5-มม-10-ชิ้น) | 20 บาท | ต้องยืนยันสต็อก; 20บาทต่อ10ชิ้น ใช้14จุด ซื้อ2ถุง; รู4.6mmเป็นค่าเริ่มทดลองทางออกแบบ ไม่ใช่ค่าทดสอบผ่าน ไม่ใช่ชื่อM3×6×4ในR1 |
| TH10 | [A3144 / A343 (IC) / ArduinoAll](https://www.allnewstep.com/product/351/a3144-a3144e-oh3144e-hall-effect-sensor) | 10 บาท | หน้าเว็บระบุพร้อมส่ง; ตัวIC ไม่ใช่โมดูล ใช้ขนาดTO92เดิมชั่วคราว รอวัดรวมขา/ฉนวน |
| TH11 | [DS18B20 TO92 / SG00085 / Arduitronics](https://www.arduitronics.com/product/383/ds18b20-temperature-sensor) | 25 บาท | หน้าเว็บระบุพร้อมส่ง; 2ตัว คงallowanceaux_sensorsเดิมจนชั่งรวม |
| TH12 | [Neodymium disc Ø3×2mm / KACHA](https://www.kacha.co.th/product/round-magnet/) | รอ | เลือกØ3หนา2และยืนยันสต็อก; ไม่ใช้ราคาเริ่มต้นของvariantอื่น ต้องยืนยันราคา2ลูกและเกรดแม่เหล็ก |
| TH13 | [Round PU Ø5mm BELT MASTER RBR / BELT MASTER (Shopee Thailand)](https://shopee.co.th/Ø-5mm-สายพานกลมแบบผิวหยาบ-BELT-MASTER-RBR-PU-i.502081560.29785878550) | รอ | sellerระบุกรุงเทพฯ; รอยืนยัน; ขอราคาความยาวขั้นต่ำและเชื่อมเป็นวง; คำนวณpitch lengthจากR2แต่ระยะstretch/รอยต่อรอทดลอง |
| TH14 | [Hex bolt12.9 M8×80 / 50pcsbox / KOH Inter](https://www.kohinter.com/product/63387-76708/hex-bolt-129-m8x80-จำนวน50กล่อง) | รอ | ต้องยืนยัน; CADใช้หัวหกเหลี่ยม13mm nominal; ต้องขอแบ่งขาย1ตัว และ drawing/headheight/partialthread22mm ของSKU ห้ามแทนsocketheadเกลียวตลอดโดยไม่ตรวจ |
| ALT14 | [Socket head12.9 M8×80 fully threaded / JSP Store](https://www.jspstore.com/product/51275-48815/น็อตหัวจมดำแข็ง-m8x80-เกรด-129-เกลียวตลอด) | รอ | ต้องยืนยัน; มีในไทยแต่หัว/เกลียวต่างจากCAD ไม่เลือกแทนอัตโนมัติ |
| TH15 | [M3 countersunk screws / 5312 / BFAST](https://www.bfastshop.com/product/5312/) | รอ | ต้องยืนยัน; URLเดิมเปิดไม่ได้ในรอบนี้ ราคา/ความยาวต้องตรวจอีกครั้ง ใช้BOMสกรูในASSEMBLY ไม่ยืนยันจากราคาเก่า |
| TH16 | Ø3×57mm grooved hinge pins / E clips / ร้านกลึงไทยตามMACHINING.md | รอ | ต้องยืนยัน; ชิ้นเฉพาะCAD ต้องกลึงตัด57mm+ร่องEclip ไม่พบสินค้าสำเร็จตรงแบบ/ใบเสนอราคา |
| TH17 | UHMW-PE3mm nose skid / ร้านตัด/กลึงไทยตามMACHINING.md | รอ | ต้องยืนยัน; ชิ้นตัดตามCAD ไม่พบรายการสำเร็จตรงแบบ/ใบเสนอราคา |
| TH18 | [16AWG silicone, XT30pairs×3, fuse30A+holder / FPVONLY](https://www.fpvonly.com/product/7205/xt60-xt30-wire-14awg-16awg-หัวต่อพร้อมสายไฟ-ตัวผู้-ตัวเมีย-มีสายพร้อมใช้งาน-ปลั๊กต่อพร้อมสาย) | รอ | ต้องยืนยัน; หน้ารวม25–30บาท/ชิ้นหลายvariant รายละเอียดเป็นXT60/14AWG ไม่ใช้กับXT30โดยอัตโนมัติ ต้องยืนยันXT30/16AWGและราคา3คู่ fuse/holderแยก รอวัดlink |
| TH19 | [GEPRC Battery Strap5pcs / FPVONLY](https://www.fpvonly.com/category/battery-accessory/32) | รอ | ต้องยืนยัน; หมวดแสดง200–230บาทหลายvariant ต้องหารุ่นกว้าง10mm/ยาวพอกับ850batteryก่อนซื้อ/ตรวจslots |
| TH20 | [IMAX B6/B6AC80W+adapter / Cybertice](https://www.cybertice.com/product/tag/80w-charger) | รอ | ต้องยืนยัน; มีlistingเครื่องชาร์จแต่ยังไม่ยืนยันราคา/SKU/แท้/charging mode; ผู้ใช้ยังไม่ซื้อ ไม่หักเป็นของที่มีอยู่ |
| TH21 | Bluetooth gamepad supported by Bluepad32 / รอเลือกmodelจากร้านไทย | รอ | ต้องยืนยัน; ห้ามถือจอยPS4cloneทุกตัวว่าใช้ได้ ต้องยืนยันmodelและจับคู่จริง ไม่พบรายการที่ยืนยันครบ |
| ALT01 | [DCM068 / Mechashop](https://www.mechashop.com/product/detail/DCM068) | 190 บาท | ผลค้นระบุมี2ตัว แต่ต้องใช้4; stockข้อมูลcrawl3สัปดาห์ก่อน ต้องยืนยันสด ไม่รวมจำนวนสองเว็บเป็น4โดยยังไม่รู้คลัง/ล็อต |
| ALT02 | [SURPASS C3536 V2 1300KV / SKU-02372 / UDSHOBBY](https://www.udshobby.com/product/tag/surpass) | 840 บาท | listingรวม1500KV; ต้องยืนยันvariant/stock/drawing/เพลา/กระแส; ทางเลือกยังไม่ใช้ในCADหรือยอดDYS1250 |
| REF07 | [DOGCOM8503S UCELL / Unmanned Tech](https://www.unmannedtechshop.co.uk/products/dogcom-850mah-150c-3s-11-1v-ucell-series) | ไม่ใช้ราคาUK | รุ่น3S850UCELL/XT30ตรงชนิด แต่ไม่พบdimension/mass; ไม่ใช้shippingmassแทนมวลแบต |

## ข้อมูลที่นำเข้า CAD R2

- ESC V2 จากABC Flying:68×25×8mm/39g แทนกล่อง55×25×12mm/35g จัดตำแหน่งใหม่และเผื่อทางออกสายสองปลาย
- ESP32 Mikroelec:XY51.5×28.5mm; ความสูง14mmเดิมรอวัด
- M3insert Friend Robot:OD5mm/ยาว4mm แทนOD4/ยาว6 รู4.6mmเป็นสมมติฐานเริ่มทดลองเท่านั้น coupons4.4–4.8mmขั้น0.1
- IMU Cybertice:XY21×16mmตรงแบบเดิม; ความสูงและมวลยังnominal
- ลูกปืนSunrise608ZZ:8×22×7mmตรงแบบเดิม; มวลยังnominal
- JGA FromFactory:OD25mmตรงแบบเดิม; รูยึด/บ่า/เพลา/มวล/กระแสยังไม่ยืนยัน
- แบต850mAhและมอเตอร์อาวุธคงnominalเดิม เพราะยังไม่มีSKUสต็อกไทยพร้อมข้อมูลเพียงพอ ไม่ใช้สเปกคนละvariantผสมกัน

ข้อมูลเว็บอยู่ใน`catalog.values`; `actual`ยังnull และ`verified`ยังfalseทั้ง27รายการ ค่าที่วัดจริงมีลำดับเหนือค่าเว็บเสมอ

## งบเมื่อยังไม่ได้ซื้ออะไร

รายการที่มีราคาตรงหน่วย:มอเตอร์ขับ4×190=760,ESC490,ESP32180,DRV2×75=150,IMU80,Hall10,DS18B202×25=50,insert2ถุง×20=40,ลูกปืน2×9=18 รวมก่อนแบต1,778บาท เพิ่มแบตSKU-08923 490 รวม **2,268บาท** เป็นเพียงยอดบางรายการ

ยังขาด:มอเตอร์อาวุธ จอย เครื่องชาร์จ connector/fuse/wiring สกรูอื่น แม่เหล็ก สายรัด สายพาน แกน/คลิป skid ชิ้นโลหะ/กลึง ชิ้นทดลอง พิมพ์เต็ม ส่ง และเงินเผื่อ รวมที่เหลือต้องไม่เกิน **3,732บาท** จึงจะอยู่ในงบ6,000 ไม่ถือว่ามีESP32หรือchargerอยู่แล้ว และไม่ใช้ราคา564ของมอเตอร์นำเข้าเป็นราคาสต็อกไทย

## รายการที่ต้องขอร้านเพิ่มก่อนซื้อ

1. FromFactory DCM068: drawing400rpmจริง พร้อมความยาวตัว/เพลา รูM3/ความลึก บ่า หน้าแบน น้ำหนักและstallcurrent
2. มอเตอร์อาวุธ:SKU1250KVที่อยู่ในไทย ราคาและdrawingครบ อย่าใช้longshaftโดยไม่ตรวจ
3. FPVONLY: SKU-08923 DOGCOM3S850150CXT30 ขนาด/มวล/รูปฉลาก/ยืนยันราคา490และสต็อกหน้าเว็บ9ก่อนซื้อ
4. ModuleMore:PCBรวมterminal/height/massและค่าRlim เพื่อเช็ก2มอเตอร์ต่อบอร์ด
5. KOH:แบ่งขายM8×80หัวหกเหลี่ยม12.9 หน้าหัวและความยาวเกลียว; คลิปและpinเป็นชิ้นทำตามแบบ
6. ร้านพิมพ์/กลึง:ใบเสนอราคาจากไฟล์R2และshopprofile; ไม่ติดต่อร้านหรือสั่งซื้อในรอบนี้

## กลุ่มข้อมูล27รายการ

| hardware key | แหล่ง / สถานะ |
|---|---|
| drive_Front_L | TH01 |
| drive_Front_R | TH01 |
| drive_Rear_L | TH01 |
| drive_Rear_R | TH01 |
| weapon_motor | TH02 |
| battery | TH07 |
| esc | TH03 |
| esp32 | TH04 |
| drv_left | TH05 |
| drv_right | TH05 |
| imu | TH06 |
| disconnect | TH18 |
| bearing_608 | TH08 |
| hinge_pin | TH16 |
| insert_m3 | TH09 |
| nut_m3 | TH15 |
| hall_sensor | TH10 |
| dead_shaft | TH14 |
| clips | TH16 |
| belt | TH13 |
| skid | TH17 |
| rotor_screws | TH15 |
| baseline_fasteners | TH15 |
| revision_fasteners | TH15 |
| wiring | TH18 |
| aux_sensors | TH11 + TH12 |
| straps | TH19 |

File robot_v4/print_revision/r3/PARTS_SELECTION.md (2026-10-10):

# ชุดอะไหล่ R3 — คัดตัวเลือกแล้ว ยังไม่ล็อกซื้อ

ตรวจเว็บ 10 ต.ค. 2026; [ข้อมูลเว็บที่ปิดเพิ่ม](WEB_CONFIRMED.md) มีรุ่นย่อย ราคาและแบบขนาดตรงรุ่นแล้ว ยังไม่มีอะไหล่จริงหรือคำตอบยืนยันจากผู้ขาย ชุดหลัก/สำรองด้านล่างเป็นชุดผู้สมัคร **ยังไม่ใช่ชุดที่ยืนยันว่าเข้ากันได้** รายการที่เป็นร้านเดียวกันไม่ถือเป็นแหล่งสำรองอิสระ ข้อมูล `actual` ทุกกลุ่มยังว่าง

| รายการ | ชุดหลักสำหรับปิดข้อมูล | ชุดสำรอง | สิ่งที่ยังขาด |
|---|---|---|---|
| ขับ 4 ตัว | DCM068 JGA25-370 12V400 / FromFactory–Mechashop | [AEI.th JGA25](https://shopee.co.th/JGA25-370-มอเตอร์เกียร์-GEAR-MOTOR-DC-6V-12V-24V-มีของพร้อมส่งทันที-!!!!-i.117988183.25015475539) | เว็บร้านหลักแสดง stock ขัดแย้ง 0/2/พร้อมส่ง; สำรองไม่เปิด variant400; stall/torque/drawing/มวลรายตัว |
| อาวุธ | [SURPASS C3536 V2 1300KV SKU02373](http://www.udshobby.com/p/2372?pid=2373) 840บาท/instock=1 | DYS D3536-06 1250KV order281406 | หลักมีคู่มือØ35×34.5/109g/เพลาØ4ยื่น20/รู19และ25M3 ใช้CADแล้ว; Øบ่า/ความลึกเกลียว/กระแสเร่งยังขาด สำรองstockไทยยังไม่ยืนยัน |
| แบต | [GNB8503S80A](https://www.gaoneng.shop/products/gaoneng-gnb-3s-11.1v-850mah-80c-xt30-lipo-battery) / [FPVONLY3-20](https://www.fpvonly.com/product/4074/ส่งฟรี-gnb-3s-300mah-6500mah-gaoneng-แบต-lipo-battery-xt30-xt60-hv-แบตเตอรี่-แบต-อุปกรณ์-rc-รถบังคับ) | DOGCOM3S850150C UCELL08923 / FPVONLY | หลักมีขนาดเว็บ63×30×24mm/80±3g ใช้ปรับ CAD ร่างแล้ว; ราคา605และInStockตรงSKU04101ตรวจใหม่แล้ว; สาย/ปลั๊กชิ้นจริงยังขาด; สำรอง490บาทเป็นราคา8ต.ค. ขนาดไม่ทราบ |
| ESC | ABCFlying Skywalker40AV2 PN80060140 listing490 | รุ่นเดิม; ยังไม่มีแหล่งอิสระยืนยัน | 3S/มอเตอร์อาวุธ/กระแสเร่ง/stock; ไม่ถือ UBECเป็นวงจรจำกัดกระแสมอเตอร์ |
| บอร์ดขับ 2 | ModuleMore01477 listing75ต่อบอร์ด | [Cybertice RM116](https://www.cybertice.com/product/4426/โมดูลขับมอเตอร์-drv8871-h-bridge-dc-motor-driver-breakout-board-for-arduino-pwm-control-3-6a-max-int) listing165ต่อบอร์ด | 2มอเตอร์ขนาน/บอร์ด: stall และ Rlim, PCB, terminal, กระแสต่อเนื่อง/อุณหภูมิ |
| บอร์ดควบคุม | Mikroelec2990 ESP32 30pin Type-C | รุ่นเดิมจนพบแหล่งตรงบอร์ด | มวล/ขาบัดกรี/สาย/stock; ไม่ใช้ความสูง nominal14mm รับรอง actual |
| ตัดไฟ/ขั้วต่อ | XT30 loop ถอดจากนอกตัว + fuse/holder | รอรุ่นที่พิกัดผ่าน | ขนาด/กระแส/สาย/loopเข้ากับ collar; ยังไม่อนุมัติซื้อ |

[TI ระบุ DRV8871 3.6A เป็น peak](https://www.ti.com/lit/ds/symlink/drv8871.pdf) ขนาด4.9×6mmเป็นตัว IC ต้องขอขนาดบอร์ดจากผู้ขาย กระแสของมอเตอร์สองตัวต้องรวมก่อนตรวจบอร์ด ไม่ยืนยัน torque จากชื่อ JGA25 เหมือนกัน หากกระแสไม่ผ่าน ให้เลือกรุ่นบอร์ดใหม่แล้วเปลี่ยนแท่นบอร์ด/สาย/ราคา/มวลทั้งระบบ

เปลี่ยนมอเตอร์อาวุธ1250→1300ต้องคำนวณรอบใหม่: ที่3Sเต็ม12.6V และอัตราทด1:1 รอบไม่มีโหลดเชิงอุดมคติ15,750→16,380rpm (+4%) ไม่ใช่รอบใช้งานจริงหรือคำรับรอง ESC 40A R3ใช้1300ในCAD/MuJoCoแล้ว พร้อมR=.038Ω/I0=1.8Aตามคู่มือ แต่ยังไม่รับรองกระแสจริงหรือESC

จอยต้องจับคู่ ESP32/Bluepad32 ได้จริง; เครื่องชาร์จต้อง balance 3S พร้อมแหล่งจ่ายและสายแปลง ทั้งสองยังไม่มีราคายืนยัน งบแยกใน [PROCUREMENT.md](PROCUREMENT.md)

ก่อนซื้อ: ผู้ใช้ส่งคำขอใน SUPPLIER_REQUESTS.md รับ exact SKU/จำนวน/ราคา/หลักฐานไฟฟ้า และใบเสนอราคาพิมพ์2ร้าน+โลหะ2แหล่ง หากยอดครบหมวด+เงินเผื่อ300เกิน6000ให้พักการสั่งซื้อ ไม่ลดจำนวนมอเตอร์หรือความจุแบตเพื่อปิดยอด

ทางเลือกที่ตรวจเพิ่ม: ORTECH JB361130บาทมีdrawingแต่เพลายื่น11.5–12mmไม่ถึง16mmที่ดุมปัจจุบันต้องการ; CytronMDD3A320บาทมีdatasheet3Acontinuous/5ApeakและPCB48.26×41.66mm แต่ไม่แทน20×20DRVโดยไม่จัดlayoutและตรวจกระแสใหม่ รายละเอียดในWEB_CONFIRMED.md

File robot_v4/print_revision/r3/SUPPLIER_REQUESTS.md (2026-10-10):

อ่าน [WEB_CONFIRMED.md](WEB_CONFIRMED.md) ก่อนส่ง: ราคา/SKU/มิติที่เว็บปิดแล้วไม่ต้องถามซ้ำ ข้อความเต็มด้านล่างใช้ตรวจรุ่นที่จะจัดส่งและเฉพาะข้อมูลที่ยังขาด

# ชุดขอข้อมูลและใบเสนอราคา — Robot V4 Print R3

ข้อความด้านล่างเตรียมให้ผู้ใช้ส่งเอง ยังไม่ได้ติดต่อร้าน ไม่ได้จองของ และไม่ได้อนุมัติผลิต ใช้คู่กับ [PROCUREMENT.md](PROCUREMENT.md), ASSEMBLY.md, MACHINING.md และ SHOP_HANDOFF.md

## มอเตอร์ขับ — FromFactory / Mechashop DCM068

> ขอข้อมูล JGA25-370 12V 400rpm รหัส DCM068 จำนวน 4 ตัวรุ่นและล็อตเดียวกันครับ ขอราคา/ค่าส่ง/จำนวนพร้อมส่งจริง และรูปฉลากกับ drawing จากสินค้าที่จะส่ง รวมความยาวตัวมอเตอร์และเกียร์, Øตัว, Øและความสูงบ่าหน้า, Øเพลา, ความยาวเพลาที่ยื่นจากหน้าเกียร์, ความลึก/ความยาวด้านแบน, พิกัดรูยึดจากศูนย์เพลา, ขนาดเกลียวและความลึกขันปลอดภัย, น้ำหนักรวมสาย และกระแส no-load/rated/stall ที่12V ขอภาพคาลิปเปอร์ที่วัดจุดสำคัญด้วยครับ ข้อมูลนี้ใช้ทำรูและดุม CAD ก่อนพิมพ์ ไม่สามารถใช้ drawing รุ่นรอบอื่นแทนโดยไม่มีการยืนยันได้

Mechashop.com แสดง2ตัวในผลค้น แต่ Mechashop.net ระบุหมด; FromFactoryเชื่อมไปMechashopและเป็นแหล่งเกี่ยวข้องกัน ต้องให้ร้านยืนยันstockจริงครบ4 ไม่บวกstockข้ามเว็บร้านเดียวกัน และไม่ถือเป็นแหล่งสำรองอิสระ

## มอเตอร์อาวุธ — SURPASSหลัก / DYSสำรอง

> ต้องการมอเตอร์ DYS D3536 1250KV ที่มีสินค้าส่งจากไทย 1 ตัว ขอชื่อ SKU/short หรือ long shaft, รูปฉลาก/สินค้าจริง, ราคาและค่าส่ง พร้อม drawing: ความยาวตัว/Øตัว, น้ำหนักรวมสายและขั้ว, Øเพลา/ส่วนที่ยื่น, Øบ่า, ตำแหน่งและเกลียวรูยึด/ความลึกขันไม่ชนส่วนหมุน, พิกัดกระแสและ ESC ที่แนะนำบน3Sครับ กรุณาแจ้งว่าอุปกรณ์ในชุดมีอะไรบ้าง ไม่ต้องรวมใบพัด

ข้อความสำหรับ UDSHOBBY ผู้สมัครหลัก (ข้อมูลที่ยืนยันจากเว็บแล้วอ่านWEB_CONFIRMED.md):

> ขอข้อมูล SURPASS C3536 V2 1300KV รุ่นย่อย SKU-02373 โดยระบุ1300KVโดยเฉพาะครับ หน้าเว็บรวม1500KVด้วย ขอ stock/ราคา variant, drawingและมวลรวมสาย/ขั้ว, Øเพลา/ความยาวส่วนยื่น/รูยึด/ความลึกเกลียว, พิกัดกระแสและESCบน3S รวมรูปฉลากV2ของตัวที่จะส่งครับ จะใช้ตรวจความเข้ากันกับCADและรอกก่อนตัดสินใจเปลี่ยนรุ่น

R3แก้ตามคู่มือSURPASSและราคา840ของรุ่นย่อย1300แล้ว ขอเฉพาะข้อมูลที่ยังไม่เผยแพร่/ตัวที่จะส่ง: Øบ่า ความลึกเกลียว มวลรวมอุปกรณ์ stockที่ส่งได้ และเงื่อนไขESC/กระแสใช้งาน ไม่ต้องรอคำตอบเรื่องØเพลาหรือรูยึดก่อนเตรียมCADร่าง

## แบตสำรอง DOGCOM (หลักเปลี่ยนเป็น GNB ดูด้านล่าง) — FPVONLY SKU-08923

> ขอ DOGCOM3S850mAh150C UCELL XT30 ตัวเลือก3-6.DC850-150C3S UC รหัสSKU-08923 จำนวน1ก้อนครับ ข้อมูลเว็บราคา490บาท/คงเหลือ9 ขอราคาและstockปัจจุบัน พร้อมรูปฉลาก3S11.1V850mAhและขั้วXT30ของสินค้าที่จะส่ง ขอขนาดตัวแบต XYZ ไม่รวมสาย น้ำหนักรวมสาย/ปลั๊ก ความยาวสาย ตำแหน่งออกสายกำลังและbalanceplug รวมขนาดปลั๊กและระยะโค้งสายขณะประกอบครับ รายละเอียด560mAh2Sในหน้าเว็บรวมไม่ใช่รุ่นที่จะใช้

ไม่ใช้ค่ามวลกล่องส่งสินค้า หรือขนาด4S/6S850mAh แทนตัวเลือก3S; ยังต้องวัดก้อนที่ได้รับก่อนปล่อยผลิต

## บอร์ดขับ — ModuleMore SKU01477

> ขอDRV8871 SKU01477 จำนวน2บอร์ดครับ ขอขนาดPCBและความสูงรวมterminal/ขาที่บัดกรี รูยึดถ้ามี น้ำหนักรวมterminal ค่าRlimหรือกระแสlimitที่ตั้งจากโรงงาน กระแสต่อเนื่องและเงื่อนไขระบายความร้อน พร้อมภาพบอร์ดทั้งสองด้านครับ จะต่อมอเตอร์DCM068สองตัวขนานต่อบอร์ด จึงต้องตรวจstall/current-limitก่อนยืนยัน ขนาดIC4.9×6mmใช้แทนขนาดPCBไม่ได้

## สกรู/insert/สายและชิ้นประกบ

ขอราคาตาม BOM ใน ASSEMBLY.md โดยแยกขนาด/ความยาว/ชนิดหัวทุกแถวและรวมแหวน/น็อตล็อก; insert Friend Robot M3×4×5 ใช้14ตัวซื้อ2ถุง10ตัว ถามขนาด OD/ความยาวจริงก่อนเลือก coupon ที่ทดลอง

M8×80 ต้องเป็นหัวหกเหลี่ยมเกรด12.9 ตามแบบ ขอแบ่งขาย1ตัว พร้อมขนาดหัว/ความยาวส่วนเกลียวและแหวน/น็อตล็อกจริง ไม่แทนหัวจมหรือเกลียวตลอดโดยไม่ได้ตรวจ stack

XT30ต้องแยกตัวผู้/ตัวเมียและขนาดสาย16AWG ไม่ใช้ราคาตัวเลือกXT60/14AWG สายรัดต้องกว้างไม่เกิน10mmและยาวรัดก้อน850จริงได้ ขอฟิวส์/holderและขนาดlinkสำหรับcollarด้วย

## งานกลึง/ตัดโลหะ

> ขอราคาเพื่อประเมิน RobotV4PrintR3 ยังไม่สั่งผลิตครับ แนบชุดDRAFT_REVIEWและMACHINING.md ขอราคาแยกวัสดุ/จำนวนตามmanifest: แผ่นโลหะ9แบบ, ดุมโรเตอร์/รอกมอเตอร์/spacers, แกนบานพับØ3×57สองแกนพร้อมร่องEclip, skidUHMW3mm รวมcountersink ต๊าป เก็บคม และงานสวมลูกปืนที่ระบุ ขอระบุtoleranceที่ทำได้และค่าเสียหากแก้รูมอเตอร์หลังวัดของจริง ทุกชิ้นต้องใช้revisionเดียวกัน ยังมีรูยึดมอเตอร์และเพลารอdrawing ไม่ผลิตตำแหน่งเหล่านี้จากnominalครับ

## ร้านพิมพ์

> ขอใบเสนอราคาชิ้นทดลองและชุดเต็มจากRobotV4PrintR3ครับ ยังไม่สั่งพิมพ์ตัวถัง แนบTRIAL_ONLYและDRAFT_REVIEWพร้อมSHOP_HANDOFF.md กรุณาระบุเครื่อง/พื้นที่พิมพ์ใช้ได้จริงXYZ/หัวฉีด/วัสดุTPU95AและPETG/slicerและprofile พร้อมราคาsupport เก็บงาน และส่ง แยกสองช่วง ขอส่งไฟล์โครงการslicerและน้ำหนักต่อชิ้นตามmanifest โดยแยกsupportออกจากชิ้นอยู่บนรถ ตัวถังต้องพิมพ์ชิ้นเดียวประมาณ190.5×217.3×54mmก่อนbrim ขอทดลองDshaft/แกนบานพับ/insert ดุม+ยางหนึ่งชุด บานพับcarrierหนึ่งข้าง และจุดยึดฝา ตามFIT_TEST.md ก่อนครับ

หากร้านต้องการค่ารูที่ยืนยันสำหรับชิ้นทดลอง ให้ล็อก SKU/วัดอะไหล่ก่อนสร้างชุดทดลอง build ใหม่ ไม่แก้ scale/รูใน slicer เพื่อปิดงานโดยไม่แก้ต้นฉบับ

## แบบตอบกลับสั้น

| รายการที่ต้องเก็บ | คำตอบ / แนบหลักฐาน |
|---|---|
| ร้าน / SKU / variant / จำนวนพร้อมส่ง / วันตรวจ | รอยืนยัน |
| ราคาแยกหน่วยขาย + VAT + ส่ง / ระยะเวลาราคามีผล | รอยืนยัน |
| Drawing/รูปคาลิปเปอร์/ฉลากสินค้าที่จะส่ง | รอยืนยัน |
| มวลรวมสาย/ปลั๊ก / ขนาดตัว / พื้นที่สายและเครื่องมือ | รอยืนยัน |
| ข้อมูลไฟ/กระแส/รุ่นต่อเข้ากัน | รอยืนยัน |
| งานพิมพ์:เครื่อง/วัสดุ/profile/brim/support/slicerproject | รอยืนยัน |
| งานโลหะ:วัสดุ/tolerance/รูต๊าป/countersink/เก็บผิว | รอยืนยัน |

บันทึกคำตอบเว็บ/ร้านเป็น catalog หรือ quote เท่านั้น ส่วน actual ต้องได้จากอะไหล่ที่ได้รับจริง และผลfit/assemblyต้องผูกกับ SHA256 ของ build ที่พิมพ์ ไม่กรอก verified=true เพื่อข้ามขั้นตอน

## แบตหลัก GNB8503S80A — FPVONLY3-20

ขอราคา stock1ก้อน และภาพฉลากรุ่น GNB8503S80A 3S11.1V850mAh80C XT30 (3-20 8503S80A) ไม่ใช่850LiHV60/120C หรือ650/720mAhครับ ผู้ผลิตระบุ63x30x24mm/80±3g ขอวัดก้อนที่ส่งจริงพร้อมสาย/ปลั๊ก/มวลและพื้นที่ดัดสายก่อนซื้อ ราคาDOGCOM490บาทไม่นำมาใช้แทนรุ่นนี้ ขอระบุconnector discharge/balanceและchargerที่เข้ากันได้ด้วยครับ

## ร้านพิมพ์และงานโลหะ2+2

ใช้RFQ/P1_TKK3D.md,P2_Threelines.md,M1_MALIEV.md,M2_SST.md พร้อมVENDORS.mdและquote_comparison.json ข้อความเดิมข้างบนเป็นรายการละเอียดสำหรับประกอบคำขอ อย่าพิมพ์ชิ้นใหญ่จากชุดDRAFT ร้านวัดและทดลอง ผู้ใช้ประกอบเต็มเอง งบรวมจอยเครื่องชาร์จบริการและเงินเผื่อ300ภายใน6000

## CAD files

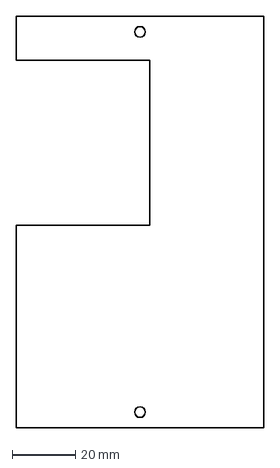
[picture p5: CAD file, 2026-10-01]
exports/DXF/Right_Side_Plate_Al.dxf
78.0 x 130.0 mm

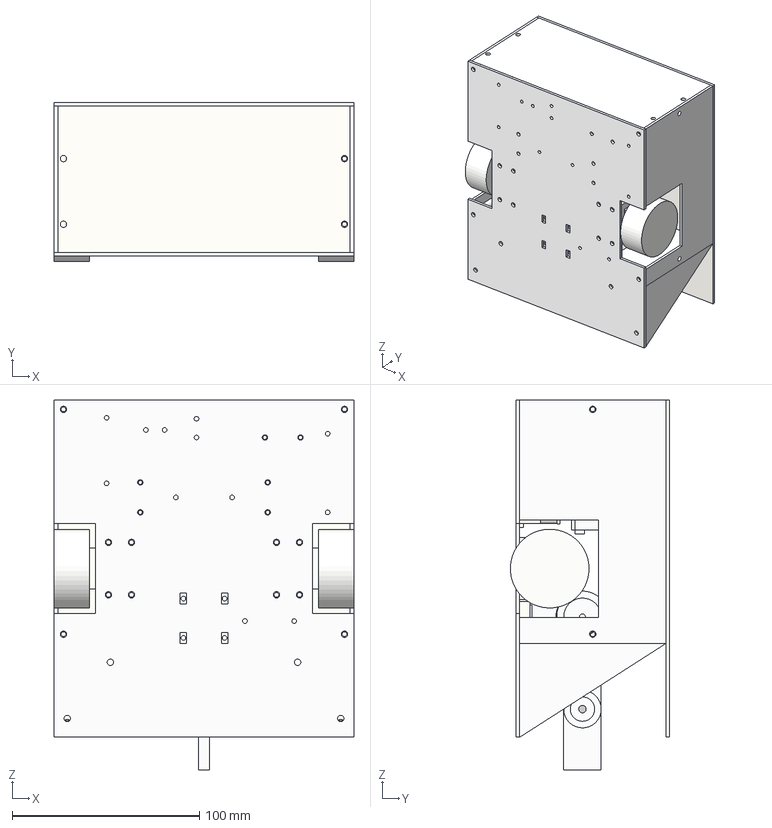
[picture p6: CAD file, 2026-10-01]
exports/ESP32_Mini_BattleBot_Competition.step
160.0 x 85.0 x 197.5 mm

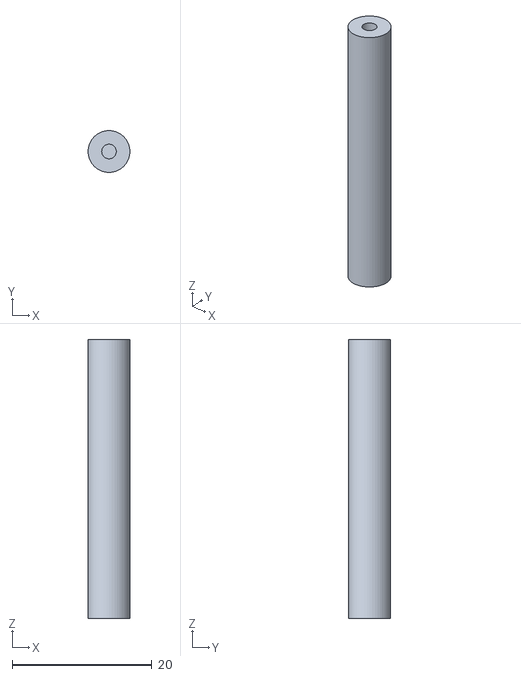
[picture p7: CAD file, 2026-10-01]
exports/STL/Disconnect_Post_2.stl
6.00 x 6.00 x 40.0

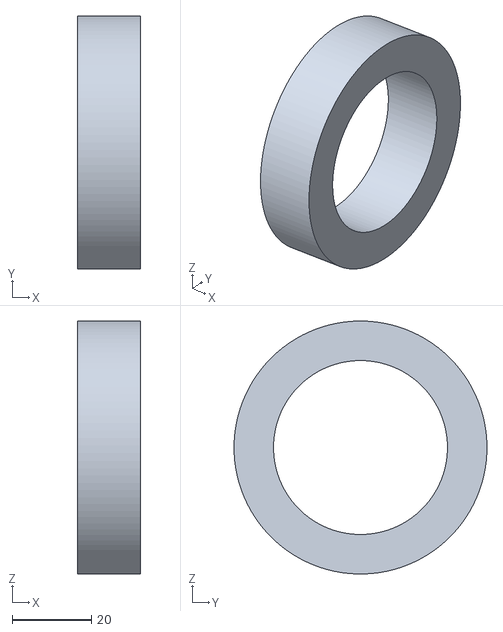
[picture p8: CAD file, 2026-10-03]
robot_v4/manufacturing/V4_Wheel_Tyre_TPU95A_x4.stl
16.0 x 64.0 x 64.0

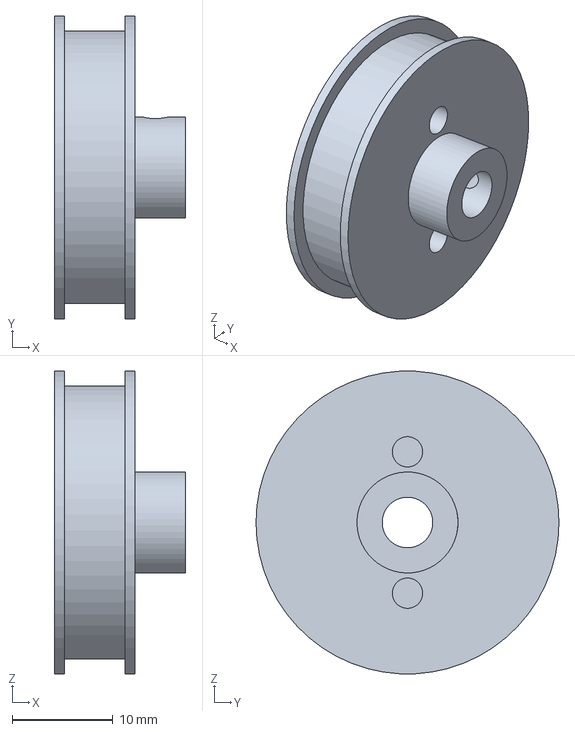
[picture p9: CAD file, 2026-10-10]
robot_v4/print_revision/catalog/output_R2/DRAFT/metal/Motor_Pulley_D30_1to1.step
13.0 x 30.0 x 30.0 mm

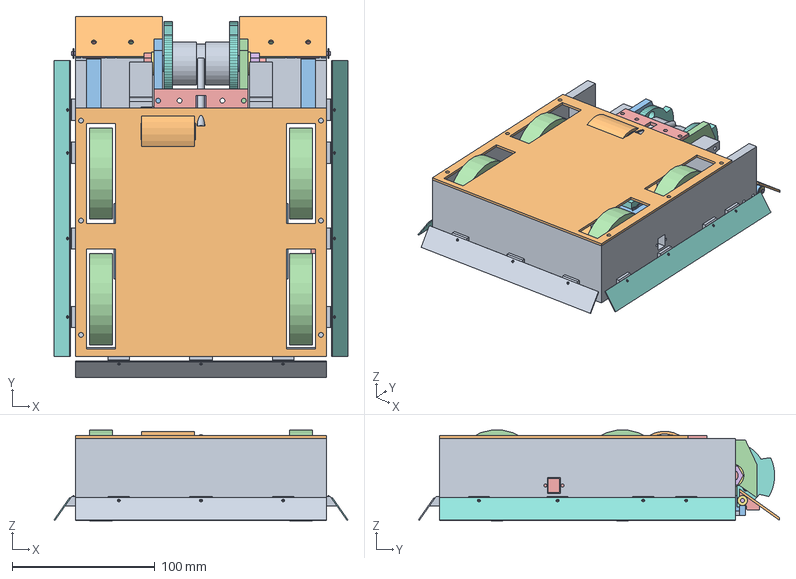
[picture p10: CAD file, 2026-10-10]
robot_v4/print_revision/catalog/output_R2/DRAFT/ROBOT_V4_PRINT_R2.step
205.8 x 252.9 x 63.5 mm
Tub_TPU
Lid_TPU_2mm
Upright_6061_6mm_L
Upright_6061_6mm_R
Weapon_Top_Brace_3mm
Weapon_Bottom_Brace_3mm
Nose_Skid_UHMW_3mm
Beater_Disc_L
Beater_Disc_R
Beater_Hub_6061_D30
Bearing_608_L
Bearing_608_R
Spacer_Outer_L_ID8.2_OD11
Spacer_Inner_ID8.2_OD11
Spacer_Outer_R_ID8.2_OD11
Dead_Shaft_M8_12.9
D3536_1250kV_Can_ENVELOPE
Motor_Pulley_D30_1to1
Weapon_Motor_Mount_3mm
Belt_Upper_ENVELOPE
Belt_Lower_ENVELOPE
Wedgelet_L
Wedgelet_R
Wedgelet_Block_PETG_L
Wedgelet_Carrier_PETG_L1
Wedgelet_Carrier_PETG_L2
Hinge_Pin_D3_L
Eclip_DIN6799_2.3_L
Wedgelet_Block_PETG_R
Wedgelet_Carrier_PETG_R1
Wedgelet_Carrier_PETG_R2
Hinge_Pin_D3_R
Eclip_DIN6799_2.3_R
Skirt_Plate_08mm_L
Skirt_Plate_08mm_R
Skirt_Plate_08mm_Rear
JGA25_370_400rpm_Front_L
Wheel_Hub_PETG_Front_L
Wheel_Tyre_TPU_Front_L
JGA25_370_400rpm_Front_R
Wheel_Hub_PETG_Front_R
Wheel_Tyre_TPU_Front_R
JGA25_370_400rpm_Rear_L
Wheel_Hub_PETG_Rear_L
Wheel_Tyre_TPU_Rear_L
JGA25_370_400rpm_Rear_R
Wheel_Hub_PETG_Rear_R
Wheel_Tyre_TPU_Rear_R
3S_850mAh_LiPo_ENVELOPE_75x35x25
Skywalker_40A_ESC_55x25x12
ESP32_DevKit_51.5x28.3
DRV8871_L
DRV8871_R
IMU_Foam_Pad_1mm
IMU_GY521_MPU6050_21x16
Hall_Post_PETG
Hall_A3144_TO92
Power_Switch_Link
Weapon_Axle_Nut_M8
Weapon_Axle_Washer_L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

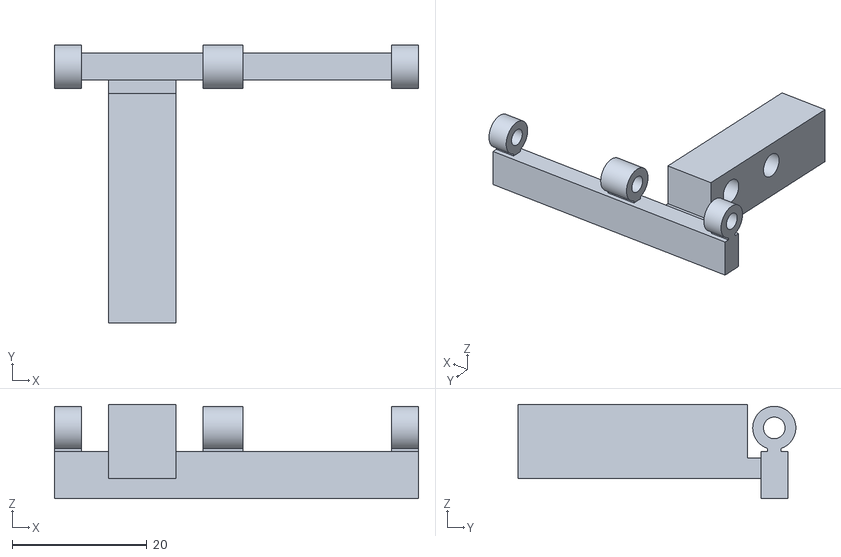
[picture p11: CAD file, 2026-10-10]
robot_v4/print_revision/catalog/output_R2/DRAFT/STL/V4_R2_Wedgelet_Block_PETG_L.stl
54.0 x 41.2 x 14.0

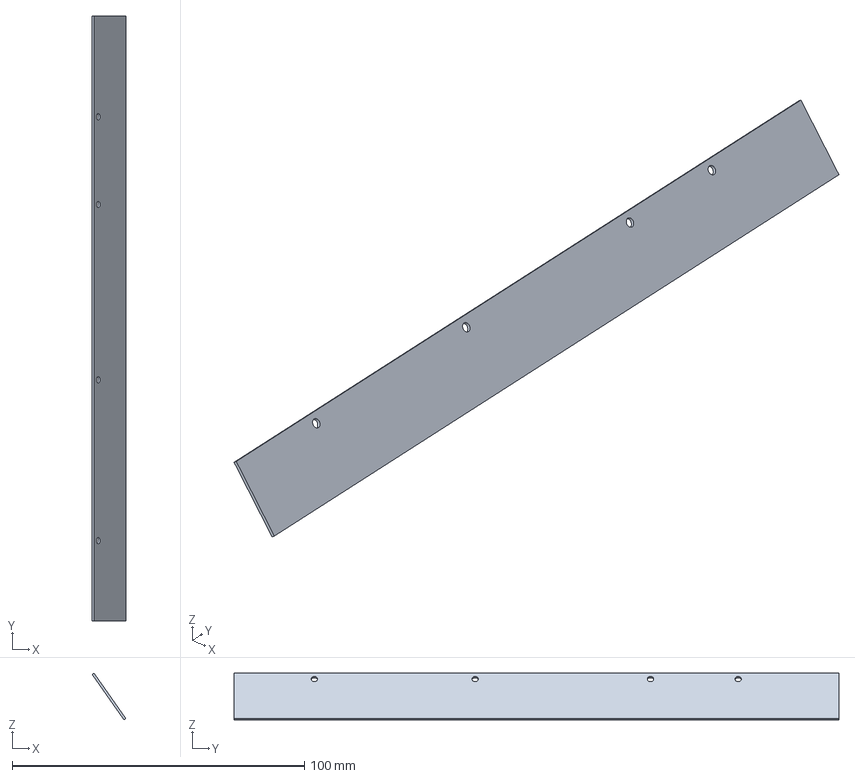
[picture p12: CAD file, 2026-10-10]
robot_v4/print_revision/output/DRAFT/metal/Skirt_Plate_08mm_R.step
11.6 x 207.0 x 16.0 mm

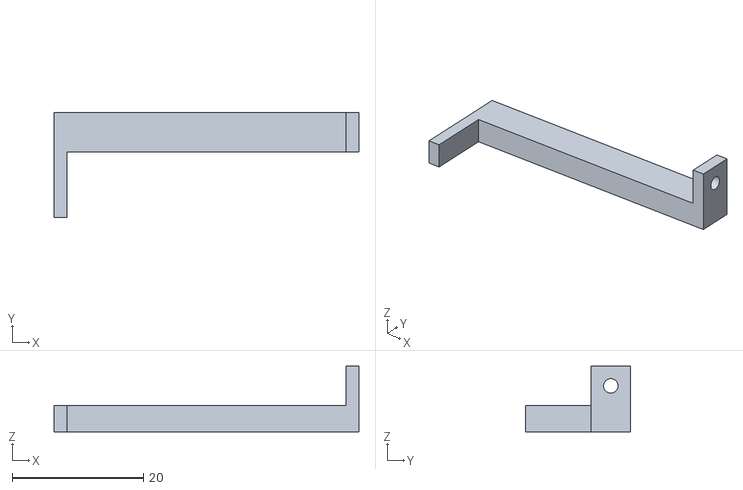
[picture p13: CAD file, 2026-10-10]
robot_v4/print_revision/output/DRAFT/STL/V4_R1_Hall_Post_PETG.stl
46.5 x 16.0 x 10.0

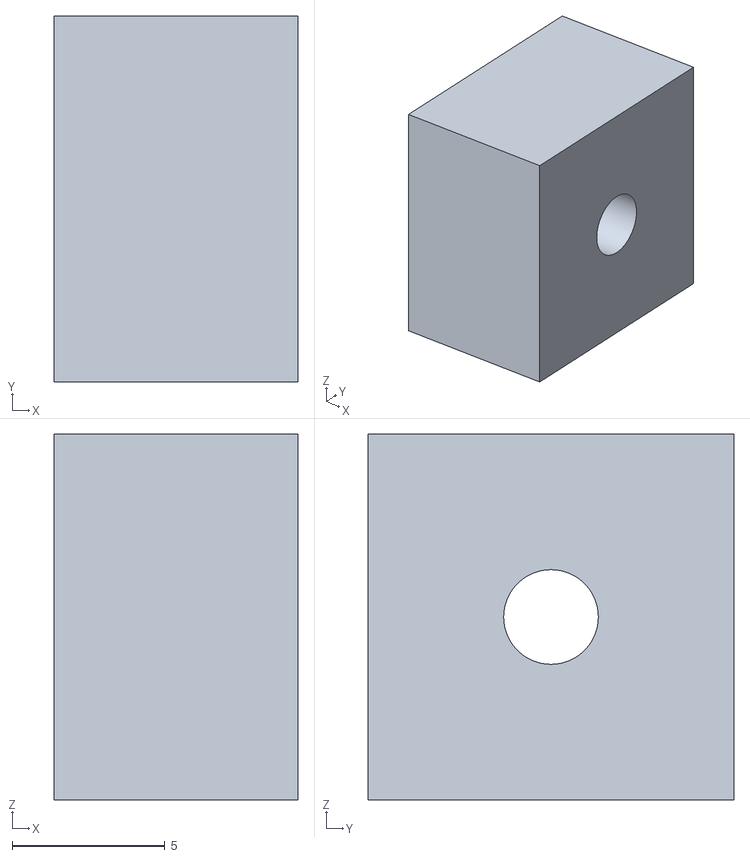
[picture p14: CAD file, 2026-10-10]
robot_v4/print_revision/output/TRIAL_ONLY/Pin_Horizontal_Clearance_010_PETG.stl
8.00 x 12.0 x 12.0

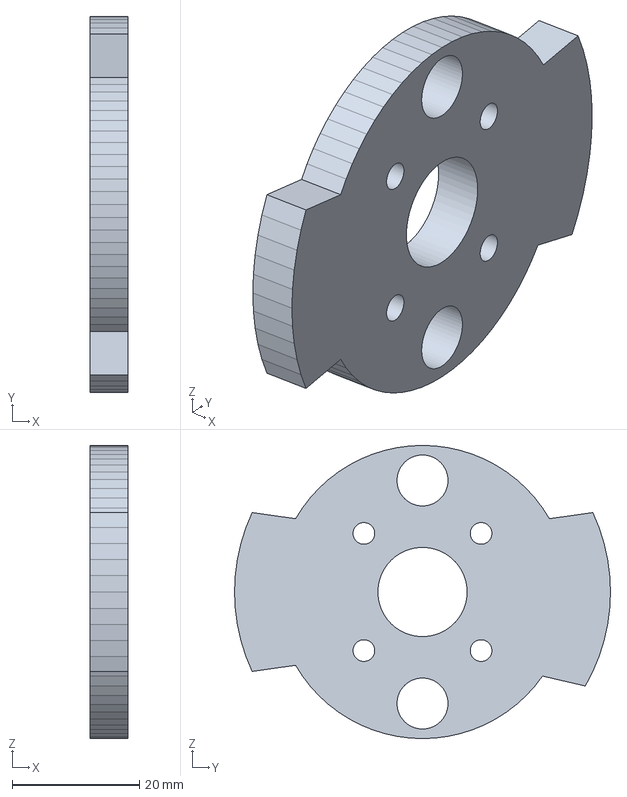
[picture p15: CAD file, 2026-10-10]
robot_v4/print_revision/r3/output_R3/DRAFT/metal/Beater_Disc_L.step
6.00 x 59.0 x 46.0 mm

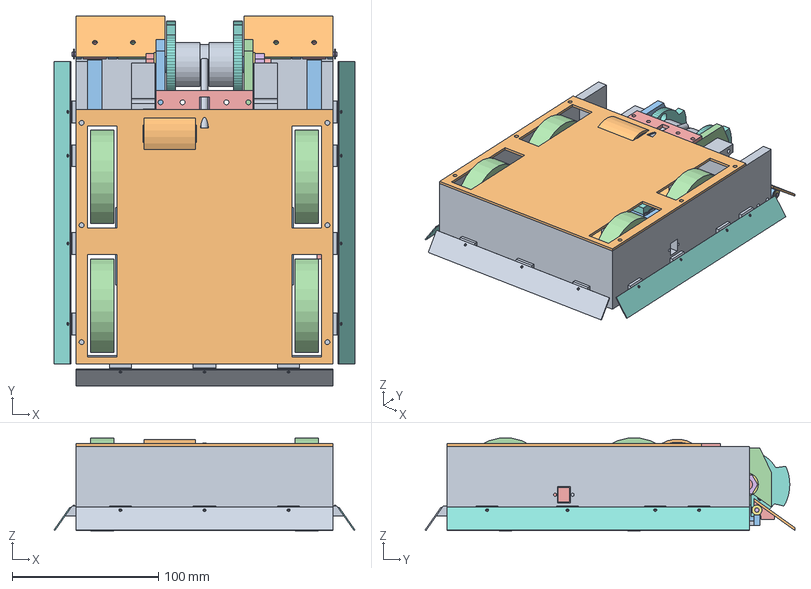
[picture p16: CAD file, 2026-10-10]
robot_v4/print_revision/r3/output_R3/DRAFT/ROBOT_V4_PRINT_R3.step
205.8 x 252.9 x 63.5 mm
Tub_TPU
Lid_TPU_2mm
Upright_6061_6mm_L
Upright_6061_6mm_R
Weapon_Top_Brace_3mm
Weapon_Bottom_Brace_3mm
Nose_Skid_UHMW_3mm
Beater_Disc_L
Beater_Disc_R
Beater_Hub_6061_D30
Bearing_608_L
Bearing_608_R
Spacer_Outer_L_ID8.2_OD11
Spacer_Inner_ID8.2_OD11
Spacer_Outer_R_ID8.2_OD11
Dead_Shaft_M8_12.9
D3536_1250kV_Can_ENVELOPE
Motor_Pulley_D30_1to1
Weapon_Motor_Mount_3mm
Belt_Upper_ENVELOPE
Belt_Lower_ENVELOPE
Wedgelet_L
Wedgelet_R
Wedgelet_Block_PETG_L
Wedgelet_Carrier_PETG_L1
Wedgelet_Carrier_PETG_L2
Hinge_Pin_D3_L
Eclip_DIN6799_2.3_L
Wedgelet_Block_PETG_R
Wedgelet_Carrier_PETG_R1
Wedgelet_Carrier_PETG_R2
Hinge_Pin_D3_R
Eclip_DIN6799_2.3_R
Skirt_Plate_08mm_L
Skirt_Plate_08mm_R
Skirt_Plate_08mm_Rear
JGA25_370_400rpm_Front_L
Wheel_Hub_PETG_Front_L
Wheel_Tyre_TPU_Front_L
JGA25_370_400rpm_Front_R
Wheel_Hub_PETG_Front_R
Wheel_Tyre_TPU_Front_R
JGA25_370_400rpm_Rear_L
Wheel_Hub_PETG_Rear_L
Wheel_Tyre_TPU_Rear_L
JGA25_370_400rpm_Rear_R
Wheel_Hub_PETG_Rear_R
Wheel_Tyre_TPU_Rear_R
3S_850mAh_LiPo_ENVELOPE_75x35x25
Skywalker_40A_ESC_55x25x12
ESP32_DevKit_51.5x28.3
DRV8871_L
DRV8871_R
IMU_Foam_Pad_1mm
IMU_GY521_MPU6050_21x16
Hall_Post_PETG
Hall_A3144_TO92
Power_Switch_Link
Weapon_Axle_Nut_M8
Weapon_Axle_Washer_L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

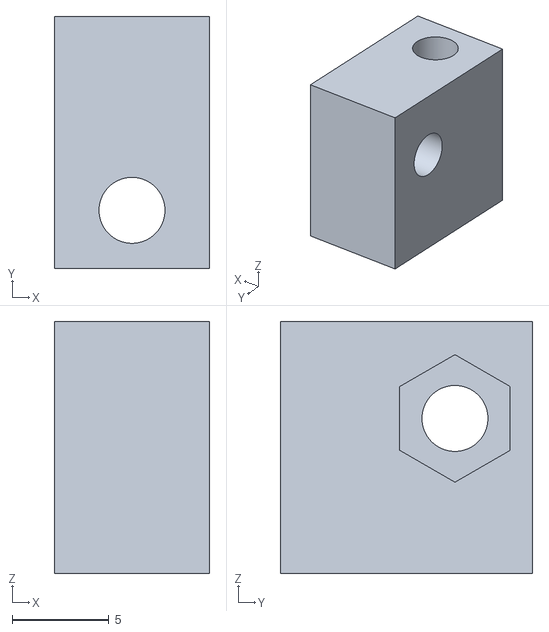
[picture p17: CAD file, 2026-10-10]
robot_v4/print_revision/r3/output_R3/DRAFT/STL/V4_R3_Weapon_Mount_Foot_PETG_1.stl
8.00 x 13.0 x 13.0

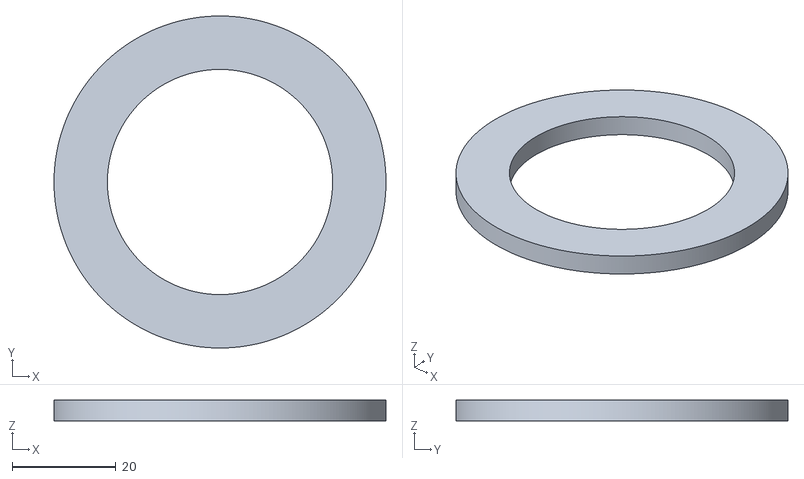
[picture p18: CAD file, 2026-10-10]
robot_v4/print_revision/r3/output_R3/TRIAL_ONLY/Tyre_Ring_ID43.4_TPU95A.stl
64.0 x 64.0 x 4.00

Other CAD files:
robot_v4/print_revision/catalog/output_R2/TRIAL_ONLY/Trial_Wheel_Tyre_TPU_Front_L.stl
robot_v4/print_revision/output/DRAFT/ROBOT_V4_PRINT_R1.step
robot_v4/ROBOT_V4_Beater.step
exports/DXF/Left_Side_Plate_Al.dxf
exports/Beater_Rotor_Concept.step
exports/DXF/Base_Plate_Al.dxf
exports/DXF/Front_Wedge_L.dxf
exports/DXF/Front_Wedge_R.dxf
exports/ESP32_Mini_BattleBot_Master.step
exports/STL/Batt_Post_1.stl
exports/STL/Batt_Post_2.stl
exports/STL/Batt_Post_3.stl
exports/STL/Batt_Post_4.stl
exports/STL/Battery_Holder.stl
exports/STL/Disconnect_Post_1.stl
exports/STL/FingerTech_Switch_Adapter.stl
exports/STL/Holder_DRV8874_A.stl
exports/STL/Holder_DRV8874_B.stl
exports/STL/Holder_ESC_Tekko32.stl
exports/STL/Holder_ESP32.stl
exports/STL/Holder_Rx_ER6.stl
exports/STL/Holder_UBEC_5A.stl
exports/STL/Rear_Panel.stl
exports/STL/Top_Cover.stl
exports/robot2_beater_concept_v1.f3d
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

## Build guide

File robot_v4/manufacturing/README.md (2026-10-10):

**อัปเดต 7 ต.ค. 2026:** ไฟล์ในโฟลเดอร์นี้เป็น **V4 เดิมก่อน Print R1** ผลตรวจใหม่พบเนื้อรอบรูบานพับเพียง 0.4 มม. จึงไม่แนะนำพิมพ์บล็อกเดิมเพื่อใช้งานจริงแม้ mesh ปิดสนิท ให้ใช้ [`ชุด R1 และชิ้นทดลอง`](../print_revision/README.md) แทน ข้อความพร้อมพิมพ์วันที่ 5 ต.ค. ด้านล่างเป็นสถานะเก่า R1 ยังเป็น DRAFT รออะไหล่และร้านยืนยัน

# V4 — ไฟล์ผลิต (3 ต.ค. 2026)

## สถานะพร้อมพิมพ์ 3D (ตรวจ 5 ต.ค. 2026)

STL ทั้ง 9 ไฟล์เป็นโมเดลปิดสนิท (ไม่มีขอบเสีย) สไลซ์ได้ แต่:
- **ส่งพิมพ์ได้เลย:** ดุมล้อ (พิมพ์ 1 ชิ้นลองสวมเพลาจริงก่อน), ยางล้อ TPU ×4, บล็อกบานพับ wedgelet L/R, carrier ใน/นอก (ชิ้น mirror ต้อง mirror ใน slicer), เสา hall sensor
- **ห้ามพิมพ์ยัง:** `V4_Tub_TPU95A_x1.stl` และ `V4_Lid_TPU95A_x1.stl` เพราะผนังยึดมอเตอร์ยังไม่มีรูน็อต, ยังไม่มีที่ยึดแบต/ESC/ESP32/DRV8871, และต้องตัดสินใจเรื่องหน้าหนัก (ย้ายแบตไปท้าย) ก่อน เพราะจะเปลี่ยน layout ภายใน
- STL อยู่ในแกนของ Fusion (Y ขึ้น) ต้องหมุนให้หน้าแบนวางบนฐานพิมพ์
- BOM คิดว่าพิมพ์เอง (TPU 450 + PETG ~100 บาท) ถ้าจ้างร้านพิมพ์ต้องขอราคาก่อน เพราะงบเหลือเผื่อแค่ ~150 บาท

ส่งออกจาก Fusion โดย `../build_robot_v4.py` (สร้างโมเดล → ตรวจ interference → ส่งออก) หน่วยเป็น **มม.** (DXF `$INSUNITS = 4`)
ตรวจแล้ว: ไม่มีชิ้นส่วนชนกัน (58 bodies รวม sensor, skirt ติดตาย, wedgelet บานพับ และ nose skid) และวงหมุนของใบเผื่อ 1 มม. ไม่โดนชิ้นอื่น. จำนวนรูใน DXF ตรวจซ้ำหลังสร้างโมเดลรอบสุดท้าย: จาน 7, แผ่นตั้ง 5, wedgelet 2, brace 2, ฐานมอเตอร์ 5
**ยังเป็นรุ่นต้นแบบแรก:** ก่อนสั่งตัดหรือพิมพ์ ต้องวัดอะไหล่จริงตามหัวข้อ "ต้องวัดของจริงก่อน" ด้านล่าง

## ชิ้นตัดเลเซอร์ / CNC (DXF = รูปร่างจริงของหน้าชิ้น)

| ไฟล์ | วัสดุ / หนา | จำนวน | ขนาด (มม.) | งานต่อหลังตัด |
|---|---|---:|---|---|
| `V4_Beater_Disc_6mm_steel_x2.dxf` | เหล็กชุบแข็งได้ **4140 หรือ Hardox 450**, 6 มม. | 2 | Ø59 (ปลายฟัน), ฐาน Ø46 | รู Ø3.4 สี่รู → **ทำ countersink 90°** สำหรับ M3 หัวจม (ทำด้านนอกของแต่ละแผ่น); รู Ø14 ตรงกลาง; รู Ø8 สองรูเป็นรูลดน้ำหนัก. **เจาะรูและทำ countersink ให้เสร็จก่อนชุบแข็ง** เพราะ 4140 ที่ 45–50 HRC กลึงหรือเจาะต่อแทบไม่ได้ หลังชุบแข็งแล้วถ่วงสมดุลคู่กับดุม. ขอบวงฐานใน DXF เป็นเส้นตรงต่อกัน 72 ช่วง (ห่างจากวงกลมจริงไม่เกิน 0.03 มม.) ไม่มีผลต่อสมดุลเพราะรูปทรงสมมาตร |
| `V4_Upright_6mm_6061_x2.dxf` | อะลูมิเนียม 6061-T6, 6 มม. | 2 (ซ้าย/ขวาเหมือนกัน) | 48 × 50 | รู Ø8.2 สำหรับแกน M8; รู Ø2.5 สี่รู → **ต๊าป M3 ทะลุ** (สกรู M3×20 ขันจากด้านในตัวรถผ่านบล็อก TPU เข้ามา); **ต๊าป M3 ลึก 8 มม. ที่ขอบบนและขอบล่าง** ตรงแนว brace (ห่างจากแผ่นตั้งอีกแผ่น 60 มม. ศูนย์ถึงศูนย์ ที่ระยะ 5 มม. จากขอบหลังของแผ่น) |
| `V4_Wedgelet_2mm_steel_x2_mirror.dxf` | เหล็กสปริงหรือเหล็กชุบแข็ง 2 มม. (หรือ Hardox ถ้ามี) | 2 (ชิ้นที่สองกลับด้าน) | 61 × 34.4 | รู Ø3.4 สองรู (ที่ x 49 และ 75 จากแนวกลาง) → countersink 90° ด้านบน. **ลับขอบหน้าให้คม** (ขอบที่อยู่ห่างจากรู); ขันลงบน carrier PETG ของบานพับ |
| `V4_Skirt_Side_0.8mm_Al_x2.dxf` | อะลูมิเนียม 5052, 0.8 มม. | 2 | 207 × 19 | skirt ข้าง (แผ่นเรียบ ยึดตายเอียง 35° บนขายึดที่พิมพ์ติดถาด) มีรู Ø2.2 สี่รู; ลบคมขอบล่าง |
| `V4_Skirt_Rear_0.8mm_Al_x1.dxf` | อะลูมิเนียม 5052, 0.8 มม. | 1 | 176 × 19 | skirt ท้าย มีรู Ø2.2 สามรู |
| `V4_Brace_3mm_6061_x2.dxf` | อะลูมิเนียม 6061, 3 มม. | 2 (บน/ล่างเหมือนกัน) | 66 × 10 | รู Ø3.4 สี่รู: ห่างกัน 60 มม. (เข้าแผ่นตั้ง) และ 30 มม. (nose skid ใช้กับ brace ล่าง) |
| `V4_Weapon_Motor_Mount_3mm_6061_x1.dxf` | อะลูมิเนียม 6061, 3 มม. | 1 | 36 × 44 | รูกลาง Ø10 และรู M3 แบบกากบาท 16 × 19 มม. — **ยังไม่ได้เทียบกับมอเตอร์จริง** และยังไม่มีรูยึดเข้าตัวถัง (ต้องเจาะเพิ่มหลังวัด) |

ระยะ, ตำแหน่ง และขนาดรูทั้งหมดอ่านได้จาก DXF ไม่ต้องวัดจากรูป

## ชิ้นกลึง (ยังไม่มีไฟล์ DXF — ส่งรายละเอียดนี้ให้ร้าน)

**ดุมโรเตอร์ `Beater_Hub_6061_D30`:** ทำจาก 6061-T6 (ดูรูปทรงจาก STEP ได้)
- ขนาดเปล่า: Ø30 × ยาว 40 มม. เจาะรูทะลุ Ø22 ทั้งท่อนให้ลูกปืน 608 (วงนอก Ø22) อัดแน่น — ดุมหมุนพร้อมวงนอกของลูกปืน จึงต้องแน่น ไม่ใช่หลวม: ใช้ระดับ N7 (ประมาณ 21.985–22.000) หรือ +0/−0.01 **ไม่ใช่ H7** (H7 คือรูหลวม ลูกปืนอาจหมุนฟรีในดุม) ให้ปรึกษาร้านกลึงและลองสวมลูกปืนจริงก่อน
- ร่องสายพานตรงกลาง: กว้าง 6 มม. ลึก 1.5 มม. (เหลือ Ø27) สำหรับสายพานกลม PU 5 มม.
- ที่ปลายทั้งสองข้าง ต๊าป M3 สี่รู (ดอก 2.5) ลึก 8 มม. บนวง Ø26 ห่างกันมุม 90° (ที่ 45°, 135°, 225°, 315° จากแนวฟัน) ให้ตรงกับรูในจาน

**รอกมอเตอร์ D26:** ใช้ 6061 Ø26 กลึงร่องเหมือนดุม รูกลางตามเพลามอเตอร์จริง (D3536 ทั่วไปเพลา 5 มม.) ยึดด้วยสกรูตัวหนอน (grub screw) M3; **เจาะรู Ø3 ลึก 2 มม. ที่หน้าด้านนอก (ฝั่งตรงข้ามมอเตอร์) รัศมี 7 มม. สำหรับฝังแม่เหล็กของ hall sensor** และเจาะอีกรูตรงข้ามกัน (180°) ใส่แม่เหล็กลูกที่สอง**กลับขั้ว** เพื่อให้รอกสมดุล A3144 ตรวจจับได้แค่ขั้วใต้ จึงยังนับ 1 ครั้งต่อรอบ (ทดสอบทิศขั้วด้วยมือก่อนติดกาว)

**แหวนรองแกน (spacer) 6061, รูใน Ø8.2 × โตนอก Ø11:** ยาว 7 มม. สองตัว และยาว 26 มม. หนึ่งตัว
ลำดับบนแกนจากซ้ายไปขวา: แผ่นตั้ง | spacer 7 | วงในลูกปืน | spacer 26 | วงในลูกปืน | spacer 7 | แผ่นตั้ง
เมื่อขันน็อตแกน ชุดนี้จะถูกบีบแน่น โรเตอร์จึงไม่เลื่อนไปถูแผ่นตั้ง (ระยะห่างข้างละ 1 มม.). spacer 7 มม. ลอดผ่านรู Ø14 ของจานโดยไม่แตะจาน

**แกน:** ใช้สกรู M8 × 70 **เกรด 12.9** พร้อมแหวนและน็อตล็อก (เกรด 8.8 ไม่ผ่านการคำนวณ)

## ชิ้นพิมพ์ 3D (STL)

| ไฟล์ | วัสดุ | จำนวน | ขนาด (มม.) | ตั้งค่าพิมพ์ที่ใช้ในการคำนวณน้ำหนัก |
|---|---|---:|---|---|
| `V4_Tub_TPU95A_x1.stl` | TPU 95A | 1 | 176 × 216 × 53 | ผนัง 4 ชั้น, infill gyroid 60% (≈85% ของมวลตัน ≈470 กรัม รวมฝา). ต้องใช้ฐานพิมพ์อย่างน้อย 220 × 220 มม. วางพื้นถาดลงฐาน |
| `V4_Lid_TPU95A_x1.stl` | TPU 95A | 1 | 176 × 174 × **2** | วางแบน (ลดจาก 3 มม. เพื่อชดเชยน้ำหนัก skirt) |
| `V4_Wheel_Hub_PETG_x4.stl` | PETG | 4 | Ø44 × 16 | รูกลางเป็นรูป D สำหรับเพลา 4 มม. (แบนลึก 0.5 มม.) มีรูลดน้ำหนัก Ø8 จำนวน 5 รู — ลองพิมพ์ 1 ชิ้นแล้วเทียบกับเพลาจริงก่อน |
| `V4_Wheel_Tyre_TPU95A_x4.stl` | TPU 95A | 4 | Ø64 × 16, รูใน Ø44 | สวมอัดเข้ากับดุม (ทากาวได้) |
| `V4_Hall_Post_PETG_x1.stl` | PETG | 1 | 4 × 8 × 36 | เสาสำหรับ hall sensor A3144 ติดกาวหรือสกรูกับพื้นถาดตรงตำแหน่งใน CAD; ตัว sensor ที่ติดปลายเสาจะห่างหน้ารอกมอเตอร์ 2.5 มม. **หันด้านแบนของ TO-92 เข้าหารอก** แล้วลองระยะที่มันตรวจจับได้กับแม่เหล็กจริงก่อนติดกาว |
| `V4_Wedgelet_Hinge_Block_PETG_L_x1.stl` / `_R_x1.stl` | **PETG** | อย่างละ 1 | 54 × 40 × 16.5 | ส่วนที่ยึดอยู่กับที่: spine + knuckle 3 อัน + สะพาน + รางชิดผนังข้าง มีรู Ø3.2 ให้แกนบานพับ; ผนัง 4 ชั้น infill 80% ขึ้นไป |
| `V4_Wedgelet_Carrier_Inner_PETG_x2_mirror.stl` / `_Outer_..._x2_mirror.stl` | **PETG** | อย่างละ 2 (ชิ้นฝั่งซ้ายให้ mirror ใน slicer) | 20/16 × 14 × 12.5 | carrier ที่แกว่งได้ มีผิวบนรับใต้แผ่น wedgelet รูแกน Ø3.2 และรู insert M3 สำหรับขันแผ่น |

**การหมุนชิ้นงาน:** STL ส่งออกในแกนของ Fusion (Y ขึ้น) ในโปรแกรม slicer ให้หมุนจนพื้นถาดหรือหน้าแบนวางบนฐานพิมพ์

**หลังพิมพ์ต้องฝัง heat-set insert M3 (Ø4 × 6) ทั้งหมด 14 ตัว:**
- 6 ตัวที่ขอบบนผนังข้างของถาด TPU (ยึดฝา)
- 8 ตัวในบล็อก PETG ข้างละ 4 ตัว:
  - 2 ตัวรับสกรู wedgelet (รูเอียงตั้งฉากกับแนวลาด)
  - 2 ตัวรับสกรู M3 แนวนอนที่ขันผ่านผนังข้างของถาดเข้ามา

**การประกอบบล็อก:** วางบล็อกบนพื้นหน้าของถาด ให้รางชิดผนังข้างและดันชน bulkhead ขันสกรู M3 สองตัวจากด้านนอกผนังข้างเข้ารางของบล็อก แล้วจึงขัน wedgelet ลงบนบล็อก
แรงที่ wedgelet รับตอนชนจะส่งผ่านบล็อก PETG ไปที่ bulkhead และผนังข้าง

**ข้อควรระวัง:** insert ออกแบบมาสำหรับพลาสติกแข็ง ใน TPU 95A อาจหมุนฟรีหรือหลุดได้
- ตอนนี้ insert ใน TPU เหลือแค่ 6 ตัวที่ยึดฝา ซึ่งไม่ได้รับแรงมาก
- **insert ใต้ wedgelet ย้ายไปอยู่ในบล็อก PETG แยกแล้ว** (3 ต.ค.)
- แผ่นตั้งยึดใบไม่ใช้ insert สกรูขันผ่านบล็อก TPU เข้าเกลียวในแผ่นอะลูมิเนียมโดยตรง

## Skirt (แบบสุดท้าย 4 ต.ค.: ยึดตาย สูงจากพื้น 0.5 มม.)

**ชิ้นส่วน:**
- แผ่นอะลูมิเนียม 0.8 มม. เรียบ ไม่ต้องดัด
- ขันด้วยสกรูเกลียวปล่อย M2 ลงขายึด 35° ที่**พิมพ์ติดกับถาด TPU** (ข้างละ 4 ขา ด้านท้าย 3 ขา มีรูนำ Ø1.6 ในไฟล์แล้ว)
- ขอบล่างยื่นออกจากผนังประมาณ 14 มม. และสูงจากพื้น 0.5 มม.
- **ไม่มีลวด หู หรือคลิปบานพับแล้ว**

**ปรับระดับ:**
- ขยายรู Ø2.2 บนแผ่นให้เป็นร่องยาวประมาณ 1 มม. ตามแนวลาด แล้วตั้งให้ขอบล่างสูง 0.5 มม. บนพื้นสนามจริง
- ใช้ฟีลเลอร์เกจหรือกระดาษ 0.5 มม. รองตอนขันสกรู

**ทำไมเปลี่ยนจากบานพับ (ผลจำลอง 3D ใน `../mujoco_sim/`):**
- **แบบห้อยตรง:** แบกน้ำหนักรถเหมือนเสาค้ำ
- **แบบบานพับเอียง:** ปลายลิ่มของ R3 สอดเข้าใต้ขอบแล้วงัดแผ่นขึ้น R3 มุดได้ 66% ตอนชนข้าง และ 100% ตอนชนท้าย
- **แบบบานพับใส่สปริง:** กันได้ แต่แผ่นกดพื้นรับน้ำหนักรถไปประมาณ 20% ทำให้ดันได้น้อยลงและเลี้ยวช้า
- **แบบยึดตายที่ความสูง 0–1.5 มม.:** V2 และ R3 มุดไม่ได้เลยทุกครั้งที่จำลอง และไม่แตะพื้นจึงไม่รับน้ำหนักรถ ถ้าสูง 1.5–2.5 มม. R3 มุดได้ 29% เฉพาะตอนชนท้าย

**ข้อควรรู้:**
- รถกว้าง **206 มม.**
- ถ้าพื้นสนามไม่เรียบเกิน 0.5 มม. skirt จะลากพื้นเป็นช่วงๆ

## Nose skid (4 ต.ค.)

- **ขนาด:** แผ่น UHMW (หรือพลาสติกลื่นอื่นๆ) 40 × 10 × 3 มม.
- **การยึด:** ขันใต้ brace ล่างด้วย M3 สองตัว (รู Ø3.4 ห่างกัน 30 มม.) ตรงกับรูกลางสองรูของ brace (DXF ของ brace มีรู 4 รูแล้ว ส่วน brace บนไม่ใช้รูกลาง)
- **ระยะ:** ใต้แผ่นสูงจากพื้น 1 มม.
- **ทำไมต้องมี:** V4 หน้าหนัก ตอนเร่งใบหัวจะทิ่มลงมาวางบน skid ก่อนที่ฟันใบจะแตะพื้น (ตรวจในการจำลอง 3D)

## Wedgelet บานพับ (เพิ่ม 4 ต.ค.)

**การประกอบ:**
1. ฝัง insert M3 ลงใน carrier ทั้ง 4 ชิ้น
2. ขันแผ่น wedgelet ลงบน carrier ด้วยสกรูหัวจม M3 ข้างละ 2 ตัว
3. วางบล็อก PETG ให้รางชิดผนังข้าง แล้วดันจนชน bulkhead
4. ร้อยแกนเหล็ก Ø3 **ยาว 57 มม.** จากด้านนอก (ฝั่งผนังข้าง) ผ่าน knuckle และ carrier สลับกัน จนปลายด้านในชนแผ่นตั้งยึดใบ (เหลือช่อง 0.5 มม.) แล้วใส่ **E-clip DIN 6799 ขนาด 2.3** ในร่องที่ปลายด้านนอก
   - ร่องกว้าง 0.6 มม. ลึกเหลือ Ø2.3 ห่างจากปลายด้านนอก 0.9 มม. (กลึงหรือตะไบ)
   - ด้านในไม่ต้องมีตัวกัน เพราะแผ่นตั้งยึดใบกันแกนไม่ให้เลื่อนเข้า
5. ขันสกรู M3 แนวนอนสองตัวจากนอกผนังข้างเข้ารางของบล็อก

**ช่วงการแกว่ง (ตรวจด้วย `../check_wedgelet_swing.py`):**
- −2° ถึง +14° ไม่ชนชิ้นใด
- ที่ประมาณ 15–16° แผ่นจะแตะขอบล่างของแผ่นตั้งยึดใบ ซึ่งเป็นตัวกันยก
- ตอนพัก ปลายแผ่นแตะพื้นด้วยน้ำหนักตัวเอง

**ทางส่งแรงตอนชนหน้า:** แผ่น → carrier → แกน Ø3 → knuckle PETG → spine และราง → bulkhead และสกรูผนัง
**ความแข็งแรงของ knuckle PETG และแกนยังไม่มี FEA** ต้องตรวจหลังทดสอบชนทุกครั้ง

## ต้องวัดของจริงก่อน (CAD ยังเป็นค่าประมาณ)

1. **JGA25-370:**
   - ระยะรูยึดที่หน้าเกียร์ และขนาดบ่าหน้า ตอนนี้ผนังยึดมอเตอร์มีแค่รูเพลา Ø8 ยังไม่มีรูน็อต
   - **ความยาวเพลา** ต้องยาวพอผ่านผนัง 4 มม. + ช่องว่าง 2 มม. + เข้าดุมล้อ 16 มม. คือราว 16 มม. ขึ้นไป ถ้าเพลาสั้นกว่านี้ ต้องย้ายดุมล้อเข้าด้านใน หรือใช้ coupler
2. **D3536:** รูปแบบรูยึดด้านหลังมอเตอร์ และเส้นผ่านศูนย์กลางเพลา
3. **แบต, ESC, ESP32, DRV8871:** ตอนนี้เป็นแค่กล่องแทนขนาด ยังไม่มีที่ยึดในตัวถัง ใช้สายรัดหรือเทปโฟมยึดไปก่อน แล้วพิมพ์ที่ยึดเพิ่มทีหลัง
4. **สวิตช์/ตัวตัดไฟ:** ตอนนี้มีแค่รู Ø6 ที่ผนังขวา ต้องปรับตามรุ่นที่ซื้อจริง
5. **น้ำหนัก:** ชั่งตัวถังที่พิมพ์เสร็จ ถ้าหนักกว่า 470 กรัม ให้ลด infill เพราะน้ำหนักรวมตามการคำนวณเหลือเผื่อแค่ประมาณ 100 กรัม

## ความแข็งแรงที่ยังไม่ได้ตรวจ

แผ่นตั้งยึดใบขันเข้ากับบล็อก **TPU** ซึ่งยืดหยุ่น ช่วยดูดซับแรงกระแทก แต่ใบอาจขยับได้ตอนชน ต้องทดสอบจริง ถ้าขยับมากให้เปลี่ยนบล็อกเป็น PETG หรือ nylon ส่วนนี้ยังไม่มี FEA

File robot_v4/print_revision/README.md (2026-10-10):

**revisionปัจจุบัน R3:** อ่าน [r3/README.md](r3/README.md); R1/R2ในไฟล์ด้านล่างเป็นประวัติ ชุดR3แยกPRINT_READYกับASSEMBLED_CHECKEDและยังรอหลักฐานจริง ใช้inputs_R3/output_R3ตามคำสั่งในR3 ไม่สร้างทับR1/R2ด้วยซอร์สใหม่

**อัปเดต8ต.ค.2026:** มี [R2 จากข้อมูลร้านไทย](catalog/README.md) แล้ว ยังเป็นDRAFTและข้อมูลอะไหล่ยังไม่วัดจริง; R1เก็บไว้เปรียบเทียบ

# V4 Print R1 — ชุดต้นแบบเพื่อปิดงานพิมพ์และประกอบ

**สถานะ: DRAFT — ยังไม่อนุมัติพิมพ์ชุดใหญ่** ผลล่าสุดและรายการที่ยังค้างอยู่ใน [output/STATUS.md](output/STATUS.md) ส่วนรายงานเครื่องอ่านได้อยู่ใน `output/build_report.json` แบบ V4 เดิมและผลจำลองเดิมยังอยู่ที่เดิม ไม่ได้ถูกแทนที่

สร้าง STEP/STL ได้โดยไม่ต้องเปิด Fusion ด้วย CadQuery ซึ่งรองรับการส่งออกทั้งสองรูปแบบ ([เอกสาร](https://cadquery.readthedocs.io/en/latest/importexport.html)) STEP เปิดใน Fusion ได้ แต่ไม่มี Fusion feature timeline; สคริปต์และ `inputs.json` เป็นแบบพาราเมตริกหลักของ revision นี้

## งานที่ทำแล้ว

- เพิ่มรูยึดมอเตอร์ขับแบบวัดแยกทั้ง 4 ตัว ช่องยึดตัวตัดไฟ ถาดแบตพร้อมสายรัด 2 เส้น แท่นอุปกรณ์ PETG และเสารอง 4 ตัวแยกพิมพ์
- เพิ่มฐาน PETG 2 ชิ้นยึดแผ่นมอเตอร์อาวุธเข้าพื้น TPU พร้อมช่องน็อต ย้ายเพลาหน้าจาก y=10 เป็น **y=18 มม.** ยกแกนมอเตอร์อาวุธจาก z=32 เป็น **42.5 มม.**
- ทำฝาครอบโค้งเหนือมอเตอร์ สูงสุด z=63 มม. ล้อยังคงสูงสุด z=64 มม. มีช่องสายพานในฝา bulkhead และ brace บน; **brace บน/ล่างใช้คนละ DXF แล้ว**
- แก้รอกมอเตอร์เป็น D30 ร่องราก D27 เหมือนดุม เพื่อให้รอบขับ **1:1** จริง เพิ่ม boss และรูต๊าปสกรูตัวหนอน พร้อมรูแม่เหล็กสมดุลสองรู
- เปลี่ยน knuckle เป็นทรงกระบอกเชื่อม spine พร้อมเนื้อรอบรูอย่างน้อย **1.6 มม.** เพิ่มน็อตโลหะและสกรูล็อกดุมล้อ รูสวมทั้งหมดปรับจากผลทดลองได้
- ส่งออกชิ้นพิมพ์เป็น Z ขึ้น วางฐาน Z=0 พร้อม carrier ซ้าย/ขวาแยกไฟล์ มี STEP assembly, DXF ชิ้นแผ่น และ STEP ชิ้นกลึง
- ตรวจ exact CAD self-interference ด้วย OpenCascade, ชิ้นชนกัน, วงหมุนใบเผื่อ 1 มม., wedgelet ทุก 1° ระหว่าง −2°…+14° และตรวจ STL โดยไม่ซ่อม mesh อัตโนมัติ
- คำนวณมวล จุดศูนย์ถ่วง และ tensor ความเฉื่อยจากชิ้น CAD/รายการน้ำหนัก แล้วใช้ใน MuJoCo โดยไม่แทนค่าจุดศูนย์ถ่วงเดิมด้วยค่าที่ปรับให้ผ่าน

ข้อมูลอะไหล่ที่ยังไม่วัดใช้ **nominal เพื่อสร้างต้นแบบเท่านั้น** ไม่ใช่ขนาดที่ร้านควรผลิตครบชุด รุ่นนี้ยังต้องยืนยันเรื่องน้ำหนัก ราคา ระยะสวม การเข้าถึงน็อตและการเดินสายจากของจริง

## วิธีปิดงานต่อ

1. กรอก [MEASUREMENTS.md](MEASUREMENTS.md) และใส่ค่าใน `inputs.json` → `hardware` → `actual` แนบหลักฐานขนาด/น้ำหนัก และระบุ `verified: true` เฉพาะรายการที่ยืนยันแล้ว
2. ให้ร้านกรอก [SHOP_HANDOFF.md](SHOP_HANDOFF.md) และขอราคา ทั้งชิ้นทดลองและชุดเต็ม ห้ามสั่งชุดเต็มหากยอดโครงการเกิน 6,000 บาท
3. สร้างชุดต้นแบบใหม่ ให้ร้านพิมพ์ชิ้นใน `output/TRIAL_ONLY` ตาม [FIT_TEST.md](FIT_TEST.md) ด้วยเครื่องและวัสดุเดียวกับงานจริง แล้วใส่ค่าที่เลือกลง `fit`
4. สร้างใหม่หลังปรับ fit ระบุผลตรวจชิ้นทดลอง พร้อม `sha256_build` ของแบบนั้น หากปรับค่าต้องสร้างและตรวจใหม่จนหลักฐานตรงกับแบบสุดท้าย
5. ร้านตรวจ slicer ทุกชิ้น ส่งไฟล์โครงการจริงและรายงานน้ำหนัก/เวลา/support กรอก `shop` กับ `slicer` และหลักฐานราคาใน `cost`
6. ตรวจทางประกอบแบบตาม [ASSEMBLY.md](ASSEMBLY.md) ด้วยอะไหล่จริง/ชิ้นทดลอง และลงผลใน `assembly` ขั้นนี้รวมการเข้าถึงสกรูและขั้วต่อ โดยไม่ต้องเปิดอาวุธ
7. สร้าง CAD → จำลอง → สร้างรายงานรวมซ้ำ แล้วใช้ `--release` เมื่อรายการค้างหมด โปรแกรมจะปฏิเสธ release หากข้อใดไม่ผ่าน

หลักฐานใช้ไฟล์จริงในโฟลเดอร์ `evidence/` เช่น รูปพร้อมไม้บรรทัด ตารางชั่ง รายงานทดลอง หรือใบเสนอราคา เก็บชื่อไฟล์ไว้ในช่อง `evidence`/`project_file`/`report_file` ให้เส้นทางสัมพันธ์กับโฟลเดอร์นี้ ข้อมูลที่ยังไม่มีให้คง `null` ไม่ใช้เลขศูนย์แทนช่องว่าง

## คำสั่งจากโฟลเดอร์โปรเจกต์

```sh
python3 -m venv .venv-v4-print
.venv-v4-print/bin/python -m pip install -r robot_v4/print_revision/requirements.txt
.venv-v4-print/bin/python robot_v4/print_revision/build.py
.venv/bin/python robot_v4/print_revision/simulate.py
.venv-v4-print/bin/python robot_v4/print_revision/build.py
.venv-v4-print/bin/python -m unittest discover -s robot_v4/print_revision/tests -v
```

MuJoCo ใช้ `.venv` เดิม หากเครื่องอื่นไม่มี ให้ติดตั้ง MuJoCo/NumPy ใน venv ของเครื่องนั้น ใช้ผลจำลองจาก build เดียวกันเท่านั้น คำสั่ง `build.py --release` จะสร้าง `output/RELEASED` เมื่อผ่านครบ ห้ามแจกโฟลเดอร์ `DRAFT` โดยเปลี่ยนชื่อเป็นชุดพร้อมผลิต

## ข้อจำกัดที่ยังเปิดอยู่

- ไม่มีเครื่องพิมพ์หรือ slicer ของร้านให้ตรวจใน session นี้ จึงยังไม่มีไฟล์โครงการ slicer หรือ G-code ที่ยืนยันแล้ว
- ยังไม่มีขนาด น้ำหนัก และผลทดลองของอะไหล่จริงครบ จึงยังไม่มีผล physical fit หรือราคารวมที่ยืนยัน
- มวลจาก CAD ยังใช้สัดส่วนเนื้อพิมพ์ประมาณ 85% สำหรับถาด/ฝา และ 80% สำหรับ PETG/ยางล้อ ต้องแทนด้วยน้ำหนัก slicer และชั่งจริง **ค่าเป้าหมาย 1,900 กรัมยังไม่ผ่าน** แม้ประมาณการอยู่ต่ำกว่า 2,000 กรัม
- โหลดล้อหลังจากสมดุลเชิงสถิตกับแรงสัมผัส MuJoCo ต่างกันได้เพราะ wedgelet สัมผัสพื้นและการเอียงตัวรถ ให้รายงานทั้งสองค่า ห้ามใช้ผลจำลองแทนการชั่งโหลดเพลาจริง
- MuJoCo เป็นโมเดล rigid body ใช้รูปชนลดรูป ไม่ใช่ FEA และยังไม่ได้ทดสอบความแข็งแรงหลังชน ผลทดสอบเฟิร์มแวร์และพร้อมแข่งอยู่นอกขอบเขต revision นี้

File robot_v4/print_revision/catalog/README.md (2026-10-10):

# V4 Print R2 — อ้างอิงข้อมูลร้านไทย / DRAFT

ปรับ R1 จากข้อมูลร้านที่อ่านได้วันที่8ต.ค.2026 เก็บ output ของ R1 เดิมไว้ทั้งหมด ไม่ใช่ชุดผลิตและยังไม่ยืนยันว่าอะไหล่ทุกตัวมีอยู่ในไทย

อ่าน [รายการจัดหาและงบ](PROCUREMENT.md), [ชุดขอข้อมูลและราคา](SUPPLIER_REQUESTS.md), [รายการร้านและข้อจำกัด](THAI_PARTS_RESEARCH.md), [สถานะ CAD](output_R2/STATUS.md), [ข้อมูลกลาง R2](inputs_R2.json), [คู่มือประกอบ](ASSEMBLY.md) และ [ผลทดลองที่ต้องทำ](FIT_TEST.md)

- ESCเป็นHobbywing Skywalker40AV2 PN80060140 ABCFlying68×25×8mm/39g อุปกรณ์ถูกจัดใหม่และขอบแท่นเปิดช่องสายสองปลาย
- ESP32Mikroelec51.5×28.5mm; ความสูง14mmเป็นnominalเดิม
- InsertFriendRobotM3×4×5 OD5/length4mm; coupons4.4–4.8mmทีละ0.1 ฝาใช้M3×6เป็นค่าเริ่มต้น
- JGAOD25,IMUXY21×16,6088×22×7ตรงค่าที่แบบเดิมใช้ ข้อมูลอื่นของชิ้นเหล่านี้ยังไม่ยืนยัน
- ไม่เปลี่ยนbattery850mAhเป็น650/720โดยเงียบๆ และไม่ใช้สเปกมอเตอร์longshaftแทนSKUที่ยังไม่เลือก
- catalog.valuesใช้ก่อนnominal; actualที่วัดจริงมีลำดับสูงสุด การปล่อยผลิตยังต้องactual/evidence/fit/shop/slicer/cost/assemblyครบ

## สร้างและตรวจซ้ำ

รันจากrootของrepository:

```sh
.venv-v4-print/bin/python robot_v4/print_revision/build.py --inputs robot_v4/print_revision/catalog/inputs_R2.json --output robot_v4/print_revision/catalog/output_R2
.venv/bin/python robot_v4/print_revision/simulate.py --inputs robot_v4/print_revision/catalog/inputs_R2.json --output robot_v4/print_revision/catalog/output_R2
.venv-v4-print/bin/python robot_v4/print_revision/build.py --inputs robot_v4/print_revision/catalog/inputs_R2.json --output robot_v4/print_revision/catalog/output_R2
.venv-v4-print/bin/python robot_v4/print_revision/preview.py --inputs robot_v4/print_revision/catalog/inputs_R2.json --output robot_v4/print_revision/catalog/output_R2
.venv-v4-print/bin/python robot_v4/print_revision/package.py --inputs robot_v4/print_revision/catalog/inputs_R2.json --output robot_v4/print_revision/catalog/output_R2 --docs robot_v4/print_revision/catalog
```

เพิ่ม `--release` ให้buildเฉพาะเมื่อหลักฐานครบ สถานะนี้ต้องปฏิเสธการปล่อยผลิต

## ข้อจำกัด

เว็บไม่ยืนยันขนาดรายตัว ความคลาดเคลื่อนหลังพิมพ์ การบัดกรี/โค้งสาย เวลารันจริง การรับแรงชน หรือเฟิร์มแวร์ เลย์เอาต์และมวลที่ผ่านในคอมพิวเตอร์ยังมีnominalของมอเตอร์ แบต และอุปกรณ์อื่นอยู่ ต้องปรับอีกครั้งเมื่อเลือกรุ่นได้ครบ

ชุดCAD/STEPนี้เปิดในFusionได้แต่ไม่มีFusionfeaturetimeline สคริปต์และJSONเป็นแหล่งพารามิเตอร์

## อัปเดตรอบจัดหา 8 ต.ค. 2026

แยกแบตFPVONLY SKU-08923 ได้ราคา490บาทและข้อมูลเว็บคงเหลือ9; ยังไม่มีdimension/massที่ใช้แก้CADได้ ไม่สร้างrevisionเรขาคณิตใหม่ในรอบนี้ ยอดบางรายการ2,268บาท เหลือเพดาน3,732บาท ยังขาดมอเตอร์อาวุธ จอย เครื่องชาร์จ งานกลึง งานพิมพ์และรายการย่อย จึงยังไม่ผ่านงบหรือปล่อยผลิต

ข้อมูลนี้แยกในprocurement_inputs/report ไม่เปลี่ยนactual/verified/costในinputs_R2; ราคาเว็บไม่ได้เป็นใบเสนอราคา ส่วนstockร้านMechashop DCM068แสดง2ตัวและต้องยืนยันครบ4

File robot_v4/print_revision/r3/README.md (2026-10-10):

# Robot V4 Print R3 — DRAFT / ยังไม่พร้อมส่งพิมพ์ชุดเต็ม

**แนวโมเดลที่ผู้ใช้ล็อก:** Z ขึ้น, พื้น XY ที่ Z=0 ใต้ล้อ, ด้านหน้า +Y ห้ามหมุนหรือสลับแกน เปิด [`ROBOT_V4_PRINT_R3_FUSION_Z_UP.f3d`](output_R3/DRAFT/ROBOT_V4_PRINT_R3_FUSION_Z_UP.f3d) เพื่อใช้ Top/Home ที่ถูกต้อง ตรวจเปิดซ้ำแล้วกริดอยู่ใต้หุ่น ตำแหน่งชิ้นส่วนทั้ง 70 ชิ้นและขอบเขตโมเดลไม่เปลี่ยน ข้อกำหนดถาวรอยู่ใน [`AGENTS.md`](../../../AGENTS.md)

R3 ใช้ R2 เป็นฐาน เก็บ R1/R2 เดิมไว้ เริ่มรอบ10ต.ค.2026 ผู้ใช้ยังไม่ได้ซื้ออะไหล่ ข้อมูลเว็บ/nominal/actualแยกกัน ชุดนี้มี STEP/STL/DXF และชิ้นทดลองสำหรับตรวจและขอราคา ยังไม่ใช่ชุดผลิตที่รับรอง

การเปลี่ยนแบบ: เลือกSURPASSC3536V2 1300KVเป็นผู้สมัครหลักตามคู่มือ; body34.5mm/109g/เพลาØ4ยื่น20mm/รู19และ25M3 ปรับรอก ฐานยึด และค่าจำลองแล้ว; Øบ่า/ความลึกเกลียวยังnominal แบตผู้สมัครหลักเป็น GNB8503S80A ขนาดเว็บ63×30×24mm/80±3g ([แหล่งผู้ผลิต](https://www.gaoneng.shop/products/gaoneng-gnb-3s-11.1v-850mah-80c-xt30-lipo-battery)) ทำถาดและตำแหน่งตามพารามิเตอร์ใหม่; actualยังไม่วัด เพิ่มcouponยางทีละ0.1mmและสร้างcouponแยกหากเพลาทั้ง4ต่างกัน ระบบ4WD TPU95A/PETG ตัวถังชิ้นเดียวและเนื้อบานพับ>=1.6mmคงเกณฑ์ตามแผน

อ่าน [ข้อมูลเว็บที่ยืนยันและแก้ CAD เพิ่ม](WEB_CONFIRMED.md), [งานปิดและผู้รับผิดชอบ](CLOSEOUT.md), [มวลและสมดุล](MASS_BALANCE.md), [อะไหล่หลัก/สำรอง](PARTS_SELECTION.md), [ร้าน2+2และคำขอราคา](VENDORS.md), [งบ](PROCUREMENT.md), [สถานะ CAD/จำลอง](output_R3/STATUS.md), [ข้อมูลกลาง](inputs_R3.json), [ทดลองสองรอบ](FIT_TEST.md), [คู่มือประกอบ](ASSEMBLY.md) และ [งานโลหะ](MACHINING.md)

## ลำดับทำงาน

1. ผู้ใช้ส่ง RFQ/คำขอข้อมูล รับราคาครบและ SKU/stock/ไฟฟ้าเข้ากันได้ ก่อนซื้อ ภายใน6000รวมเงินเผื่อ300
2. ผู้ใช้ซื้อและส่งอะไหล่ให้ร้านวัด/ชั่ง/ถ่ายหลักฐานตามmeasurement_log.json แล้วนำactualเข้าinputs_R3 สร้างใหม่
3. ร้านล็อกเครื่องวัสดุ/profileแล้วพิมพ์couponรอบ1; นำค่าที่เลือกสร้างใหม่ ร้านทดลองสวมเต็มรอบ2และบันทึกfit_log.json; ต้องเพลาครบ4และฝา5รอบ
4. ตรวจpreflight CAD mesh interference/wedge/rotor; ร้านsliceทุกชิ้น น้ำหนักจริง+slicer/สมดุล/งบครบ แล้วจำลองล่าสุด หากพลาดเป้า1900g/15%ให้ผู้ใช้ตัดสินใจจากส่วนเผื่อก่อนปล่อย โดยขั้นต่ำ2000g/10%ข้ามไม่ได้
5. `--release` ผ่านจึงสร้างRELEASEDสถานะPRINT_READY ผู้ใช้ประกอบแล้วบันทึกassembly actual/หลักฐานทั้งหมดแยกเป็นASSEMBLED_CHECKED

## สร้าง/ตรวจ

รันจาก root repository:

```sh
.venv-v4-print/bin/python robot_v4/print_revision/build.py --inputs robot_v4/print_revision/r3/inputs_R3.json --output robot_v4/print_revision/r3/output_R3
.venv/bin/python robot_v4/print_revision/simulate.py --inputs robot_v4/print_revision/r3/inputs_R3.json --output robot_v4/print_revision/r3/output_R3
.venv-v4-print/bin/python robot_v4/print_revision/build.py --inputs robot_v4/print_revision/r3/inputs_R3.json --output robot_v4/print_revision/r3/output_R3
.venv-v4-print/bin/python robot_v4/print_revision/package.py --inputs robot_v4/print_revision/r3/inputs_R3.json --output robot_v4/print_revision/r3/output_R3 --docs robot_v4/print_revision/r3
```

เพิ่ม `--release` เมื่อหลักฐานครบเท่านั้น การรันตอนนี้ต้องปฏิเสธและไม่สร้างRELEASED คู่มือ/ไฟล์ผลิตและหลักฐานถูกเก็บพร้อมSHAในชุดปล่อย `fit`/`preflight`/`electrical`/`slicer`ต้องตรงbuildล่าสุด รวมทั้งprofile hashของไฟล์ตั้งค่าจริง ห้ามเปลี่ยนscale/รู/ท่าในslicerโดยไม่ทวนtrial

หลังประกอบ:

```sh
.venv-v4-print/bin/python robot_v4/print_revision/readiness.py --inputs robot_v4/print_revision/r3/inputs_R3.json --release-report robot_v4/print_revision/r3/output_R3/RELEASED/release_report.json
```

คำสั่งตรวจประกอบต้องมีผลหุ่นเต็มจริงและชั่งมวล/โหลดล้อหลัง; ไม่ใช้ผลcouponแทนสถานะประกอบ ไม่มีเฟิร์มแวร์หรือการรับรองแข่งในชุดนี้ สคริปต์+JSONเป็นแหล่งพารามิเตอร์ STEPไม่มีFusionfeaturetimeline

ยอดเก่า2268บาทเป็นข้อมูลบางรายการ8ต.ค. ปัจจุบันเพิ่มSURPASS840และGNB605ตรงvariantเป็นยอดที่ทราบ3,223บาท; กันเผื่อ300แล้วเหลือเพดาน2,477สำหรับ17หมวดรอราคา ยังไม่ใช่ราคาทั้งโครงการและยังไม่อนุมัติซื้อหรือผลิต

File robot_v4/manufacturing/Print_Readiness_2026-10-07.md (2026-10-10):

# Robot V4 — ตรวจความพร้อมพิมพ์ 3D วันที่ 7 ต.ค. 2026

**ผล: ยังไม่พร้อมพิมพ์ครบชุดเพื่อประกอบใช้งานจริง พิมพ์ชิ้นทดลองบางส่วนได้**

ตรวจไฟล์ STL ปัจจุบันทั้ง 9 ไฟล์และโค้ดสร้าง CAD โดยไม่ได้แก้แบบ ไม่ได้เปิด slicer หรือทดสอบชิ้นพิมพ์จริง

## ผลตรวจ STL โดยตรง

ทุกไฟล์เป็น binary STL ที่อ่านได้ครบ มีผิวเชื่อมต่อ 1 ชุด ขอบเปิด 0 ขอบ non-manifold 0 ทิศทางขอบของผิวสอดคล้องกัน ไม่มีสามเหลี่ยมพื้นที่ศูนย์หรือหน้าซ้ำ และปริมาตรมีเครื่องหมายบวก ตรวจด้วย Python/NumPy โดยรวมจุดที่มีพิกัดตรงกันทุกค่า ไม่ได้ซ่อม mesh

ผลนี้ยืนยันโครงสร้าง mesh ตามการตรวจข้างต้น ไม่ได้ยืนยันว่าไม่มีผิวตัดกันเองทั้งหมด หรือยืนยันผล slicing ความแข็งแรงและการประกอบ

| ไฟล์/ชิ้น | ขนาดตามแกนแบบ X × Y × Z (มม.) | สถานะ |
|---|---|---|
| Tub TPU | 190.523 × 217.261 × 54 | รอแก้แบบก่อนพิมพ์จริง |
| Lid TPU | 176 × 174 × 2 | mesh ผ่าน แต่รอให้ layout ตัวถังจบ |
| Wheel hub PETG | 16 × 44 × 44 | พิมพ์ 1 ชิ้นทดลองสวมเพลาจริง |
| Wheel tyre TPU | 16 × ≈64 × ≈64 | พิมพ์ 1 ชิ้นทดลองคู่กับดุม |
| Hall post PETG | 4 × 8 × 36 | พิมพ์ได้ แต่ยืนยันตำแหน่งเซนเซอร์หลัง layout จบ |
| Hinge block PETG L/R | 54 × 40 × 14 ต่อชิ้น | ควรแก้เนื้อรอบรูบานพับก่อนผลิตใช้งานจริง |
| Carrier inner PETG | 20 × 14 × 12.5 | พิมพ์ทดลองร่วมกับบานพับและ insert จริง |
| Carrier outer PETG | 16 × 14 × 12.5 | พิมพ์ทดลองร่วมกับบานพับและ insert จริง |

STL อยู่ในแกน Fusion: Y ขึ้น ต้องหมุนและวางชิ้นงานให้เหมาะสมก่อนสไลซ์ ขนาดในตารางแปลงเป็นแกนแบบแล้ว

## จุดที่ยังไม่ผ่าน

1. **ตัวถังยังไม่มีรูน็อตยึดมอเตอร์ขับ** `build_robot_v4.py` สร้างผนังและรูเพลา Ø8 เท่านั้น ยังต้องวัดรูยึด บ่าหน้า และความยาวเพลาของ JGA25-370 ตัวจริง พร้อมกำหนดวิธีกันดุมเลื่อนตามแกน
2. **อุปกรณ์ภายในเป็นกล่องแทนขนาด** ยังไม่มีที่ยึดแบต ESC ESP32 และ DRV8871 ที่สร้างในตัวถัง ต้องกำหนดที่ยึด การเดินสาย และจุดเข้าถึงตัวตัดไฟ รวมถึงรูยึดฐานมอเตอร์อาวุธเข้าตัวถัง ก่อนส่งผลิต
3. **layout และการกระจายน้ำหนักยังค้าง** `STATUS.md` ระบุว่าล้อหลังรับน้ำหนักประมาณ 5% และต้องลองย้ายแบตไปท้าย จากนั้นตรวจ interference และจำลองซ้ำ งานนี้อาจเปลี่ยนตัวถังและที่ยึดภายใน จึงควรรอพิมพ์ถาดกับฝา
4. **บานพับมีเนื้อบาง 0.4 มม.** knuckle อยู่ที่ y=100…104 และสูงถึง z=16.5 รูแกน Ø3.2 มีศูนย์ที่ y=102, z=14.5 จึงเหลือเนื้อด้านหน้า ด้านหลัง และด้านบนเพียง 0.4 มม. ยืนยันจากหน้าตัด STL จริงของชิ้นขวาที่ x=36 ด้วย ข้อความเดิมใน README ที่ให้พิมพ์บล็อกได้เลยควรถือเป็นความพร้อมด้าน mesh เท่านั้น จากทางส่งแรงที่ระบุไว้ บานพับรับแรงจาก wedgelet จึงควรเพิ่มเนื้อและตรวจระยะแกว่งใหม่ก่อนจัดว่าพร้อมใช้งานจริง
5. **fit ของล้อและบานพับยังไม่ยืนยัน** ดุม OD44 และยาง ID44 เท่ากันใน CAD ไม่มีระยะสวมอัดที่ออกแบบแยกไว้ ส่วนรู D ของดุมใช้รัศมี 2.05 มม. และระนาบแบนห่างศูนย์ 1.55 มม. สำหรับเพลา nominal Ø4 แบนลึก 0.5 มม. รูแกนบานพับ Ø3.2 คู่กับแกน Ø3 เผื่อเส้นผ่านศูนย์กลางเพียง 0.2 มม. ต้องลองกับเครื่องพิมพ์ วัสดุ เพลา และ insert จริง

## ขนาดที่คู่มือเดิมคลาดเคลื่อน

- Tub ใน README ระบุ 176 × 216 × 53 แต่ STL รวมขายึด skirt เป็น **190.523 × 217.261 × 54 มม.**
- Hinge block ใน README ระบุ 54 × 40 × 16.5 แต่ความสูงรวมจริงคือ **14 มม.** (z=4…18); 16.5 เป็นระดับยอด knuckle จากพื้นสนาม
- ถ้าวางถาดตรงตามแกนบนฐาน 220 × 220 มม. ด้านยาวเหลือพื้นที่รวมเพียง 2.739 มม. หรือประมาณ 1.37 มม. ต่อข้างเมื่อจัดกลาง ต้องเช็กพื้นที่พิมพ์ที่ใช้ได้จริงและ brim ใน slicer

## ขั้นตอนถัดไป

วัดอะไหล่จริง → จบ layout และที่ยึดภายใน → เพิ่มเนื้อรอบรูบานพับและตรวจการแกว่ง → พิมพ์ดุม/ยาง/บานพับทดลอง → ตรวจสไลซ์จริง ขนาดฐานพิมพ์ support เวลาและน้ำหนัก → ส่งออก STL ใหม่ → พิมพ์ครบชุด

อ้างอิงภายใน: `build_robot_v4.py` ส่วน chassis, hinged wedgelets และ drive; `STATUS.md` งานค้างข้อ 5–7; `manufacturing/README.md` สถานะพร้อมพิมพ์และหัวข้อต้องวัดของจริงก่อน

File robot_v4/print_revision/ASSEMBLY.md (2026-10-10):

# วิธีประกอบและรายการสกรู — V4 Print R1 ต้นแบบ

หน่วยมม. ใช้ไฟล์ R1 ทั้งชุด ห้ามปนถาด ฝา brace บน หรือรอกมอเตอร์ V4 เดิมกับ R1 ตำแหน่งเพลาหน้าและมอเตอร์อาวุธเปลี่ยนแล้ว ความยาวสกรูด้านล่างเป็นค่าตั้งต้น ต้องเทียบความลึกเกลียวและหัวสกรูจริงก่อนลงผลพร้อมประกอบใน JSON

## รายการสกรูและอุปกรณ์ยึด

| จุดยึด | จำนวน | ตั้งต้น | วิธีตรวจความยาว / งานต่อ |
|---|---:|---|---|
| มอเตอร์ขับ | 8 ตามรู nominal; ใช้จำนวนรูจริง | M3 button head ×8 + แหวน OD≤7 | ผนัง 4 มี recess ด้านล้อ 1; ผ่านพลาสติก 3 + แหวนราว 0.5 เหลือเข้าเกลียวราว 4.5 ต้องไม่ชนกลไกในเกียร์ |
| ดุมล้อ | 4 | น็อต M3 + สกรูตัวหนอน M3 ×22 | ช่องน็อตเปิดด้านข้าง; เลือกความยาวให้ปลายกดเพลาด้านแบนโดยหัวไม่ชนตัวถัง/ยาง ห้ามพิมพ์เกลียวพลาสติกแทนน็อต |
| แผ่นตั้งใบ | 8 | M3 ×20 + แหวน | ผ่านบล็อก TPU 16 เข้าต๊าปแผ่น 6061 ประมาณ 4 |
| จานอาวุธ | 8 | M3 หัวจม 90° ×10 | ผ่านเหล็ก 6 เข้าเกลียวดุมประมาณ 4; countersink จานจริง ไม่ใช่รูใน DXF อย่างเดียว |
| Brace เข้าแผ่นตั้ง | 4 | M3 ×10 | ผ่าน brace 3 เข้าต๊าปขอบ 7; รูต๊าปลึกอย่างน้อย 8 |
| Nose skid | 2 | M3 หัวจม ×8 + น็อตล็อก | แผ่น 3 + brace 3; เก็บหัวให้เสมอใต้ skid ห้ามต่ำกว่า skid |
| ฝา TPU | 6 | M3 button head ×8 + แหวน | ฝา 2 + แหวน 0.5 เข้า insert ประมาณ 5.5; ทดสอบไม่ดึง insert หลุด |
| บล็อกบานพับเข้าผนัง | 4 | M3 ×12 + แหวน | ผนัง 8 + แหวน 0.5 เข้า insert ประมาณ 3.5 |
| Wedgelet เข้า carrier | 4 | M3 หัวจม ×8 | แผ่นเหล็กแนวเอียงต้อง countersink; ตรวจว่าไม่ชนแกนบานพับ |
| แผ่นมอเตอร์อาวุธเข้า PETG feet | 2 | M3 ×10 + น็อต M3 ในช่อง | ผ่านแผ่น 3 เข้า foot; น็อตวางจากด้านที่แผ่นปิด ตรวจเกลียวเต็มน็อต |
| PETG feet เข้าพื้น TPU | 2 | M3 ×20 + แหวนสองด้าน + น็อตล็อก | พื้น 3 + foot 13 =16; หัวใต้พื้นต้องไม่ต่ำถึงสนาม |
| ถาดแบตเข้าพื้น | 4 | M3 ×10 + แหวนสองด้าน + น็อตล็อก | พื้น 3 + ถาด 1.6; ใช้แหวนเล็กไม่ชน slot/แบต |
| แท่นอุปกรณ์ผ่านเสารองเข้าพื้น | 4 | M3 ×40 + แหวนสองด้าน + น็อตล็อก | พื้น 3 + เสารอง 31.6 + แท่น 2 =36.6; ตรวจส่วนยื่นและพื้นที่ขันด้วยของจริง |
| Hall post | 1 | M2 ×8 + แหวน + น็อตล็อก | มีรูผ่าน PETG foot/pื้น; เสาอยู่ห่างจานรอกและสายพาน |
| Disconnect collar | 2 | M2 ×14 + แหวน + น็อตล็อก | ผนัง 8 + collar 3; ตรวจหัวน็อตไม่ติดล้อหรือสาย |
| Skirt | 11 | M2 เกลียวปล่อย ×8 | รูนำ Ø1.6 ใน TPU; ตรวจขันไม่รูด และปรับระดับแผ่นด้วยร่องบนโลหะ |
| แกนอาวุธ | 1 | M8 ×80 เกรด12.9 + แหวน/น็อตล็อก | เปรียบเทียบ stack 66 มม. แบบใหม่จำลองหัว/แหวน/น็อตครบและมีช่องบล็อกขัน Ø21; ต้องยืนยันขนาดและเกลียวจริง |
| แกน wedgelet | 2 | เหล็ก Ø3 ×57 + E-clip DIN6799 2.3 | ร่องกว้าง0.6 ลึกถึงØ2.3 ตำแหน่งปลายตาม STEP; ไม่ตัดแกนเองโดยไม่มีร่องกันหลุด |
| Insert M3 | 14 | OD/length ตามของจริง | ฝา6, รางบล็อก4, carrier4; ไม่ใช่ insert wedgelet ในบล็อกเก่า |
| แบต/บอร์ด | 2 สายรัดแบต + 2 cable ties ต่อโมดูล5ตัว | สายรัดกว้าง≤10, ties ผ่านช่อง3.6 | รัดได้โดยไม่กดขั้วต่อหรือบีบแบต บอร์ดมีฉนวน/โฟม1มม. |

จำนวนเดิมอาจเปลี่ยนเมื่อมอเตอร์จริงมีรูต่างจาก nominal ใช้ตำแหน่งรูจาก STEP ของ build สุดท้ายเป็นหลัก ราคารวมต้องรวมรายการ R1 เพิ่มเหล่านี้

## ลำดับประกอบ

1. ทำชิ้นโลหะและเก็บคมตาม `MACHINING.md` ลองลูกปืนกับดุมจริงก่อนประกอบโรเตอร์ เก็บรอยกระแทกและรอยแตกของชิ้นพิมพ์ทดลอง
2. ฝัง insert ในฝาถาด รางบานพับ และ carrier ลองขันตาม FIT_TEST ก่อนประกอบชุดใหญ่
3. ใส่มอเตอร์ขับ ขันสกรูจากฝั่งล้อให้หัวและแหวนอยู่ใน recess ตรวจ gap ระหว่างหัวสกรูกับดุม ล็อกดุมบนด้านแบนและสวมยาง
4. ยึด PETG feet และแผ่นมอเตอร์อาวุธ โดยใส่น็อตเข้าช่องก่อนปิดด้วยแผ่นมอเตอร์ ขันมอเตอร์ตามรูจริง ลองสายพานและจุดที่ผ่าน bulkhead/ฝา/brace บน
5. ขันแผ่นตั้งและ brace ตามแบบใหม่ ใส่ spacer7–608–spacer26–608–spacer7 แล้วขันแกนตายให้แน่น โรเตอร์ต้องหมุนคล่องและไม่เลื่อนจนถูกแผ่นตั้ง ตรวจหัวสกรูจานไม่โดนชิ้นอื่น
6. ยึด nose skid หัวสกรูเสมอใต้ผิว ตั้ง skid สูงจากสนาม1มม. และ skirt0.5มม. รู skirt โลหะยังต้องขยายเป็นร่องตามคู่มือโลหะ
7. ประกอบบล็อก/carrier/แผ่น wedgelet และใส่แกน/E-clip ทั้งสองข้าง ตรวจลงพื้นเองและยกไม่ติด ความหนา knuckle/วงรับแกน carrier ของ R1เพิ่มแล้ว
8. ยึดถาดแบต ร้อยสายรัดก่อนวางแบต ยึดแท่นอุปกรณ์บนเสารองด้วยน็อตผ่านพื้น หัวน็อตใต้ถาดต้องไม่ต่ำถึงพื้นสนาม4มม. บอร์ดใช้ฉนวน/โฟม1มม.และ cable ties ผ่าน slot จัดหัวปลั๊กไว้ตาม connector keep-out ที่วัด
9. ยึด Hall post และ collar หันด้านแบน sensor เข้ารอก ใส่แม่เหล็กสองรูโดยกลับขั้วกัน ให้ sensorอยู่ห่างหน้ารอก2.5มม.ตามแบบ ทดลองตรวจจับด้วยมือก่อนติดกาว
10. เดินสายให้ไม่ผ่านช่องล้อ/สายพาน/วงหมุนใบและไม่ถูกฝาหนีบ ยึดสายด้วย ties บนแท่น ตรวจถอด link ได้จากภายนอก และถอดฝาได้โดยไม่ดึงสาย
11. ตรวจตัวถังและชุดประกอบแบบไม่เปิดอาวุธ ชั่งน้ำหนักรวมและโหลดเพลาหน้า/หลัง บันทึกหลักฐาน งานทดสอบไฟ เฟิร์มแวร์ และชนจริงยังเป็นงานถัดไป

## จุดที่ต้องวัดก่อนยืนยันความพร้อม

- ความยาวแกน M8 ต้องมีเกลียวเต็มน็อตล็อก หลังรวม stack และแหวน R1 เลือก M8×80 และเพิ่มช่องใส่บล็อกขัน Ø21 ใน TPU แล้ว ให้ยืนยันเกลียวกับน็อตจริง; ข้อมูลนี้ต้องถูกล็อกในแบบก่อน release
- มอเตอร์/เพลา/น็อตต้องตรงกับ inputs; ถ้า head/washer ที่ซื้อใหญ่กว่า recess ให้แก้ CAD ก่อนพิมพ์ ไม่เจาะหน้างานโดยไม่บันทึก
- ทดลองนำเครื่องมือเข้าทุกจุด โดยเฉพาะสกรูมอเตอร์หน้าหลัง แท่นอุปกรณ์ และสกรูฐานมอเตอร์อาวุธ ตรวจขั้วต่อจริงกับ keep-out
- น้ำหนักชิ้นพิมพ์จาก slicer เป็นประมาณการ ก่อนใช้งานต้องชั่งหุ่นจริงไม่เกิน2กก. และโหลดล้อหลังไม่น้อยกว่า10%

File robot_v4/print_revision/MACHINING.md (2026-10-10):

# งานโลหะที่ประกบ R1 — หน่วยมม.

ไฟล์ใน `output/DRAFT/metal` เป็นแบบต้นฉบับ revision เดียวกับ STL และ assembly STEP ยังรอขนาดอะไหล่จริง ไม่ใช้ไฟล์ V4 เดิมแทน brace บนหรือฐานมอเตอร์

| ชิ้น | จำนวน / วัสดุ | งานหลังตัด/กลึง |
|---|---|---|
| จาน beater | 2 / เหล็ก4140หรือHardox450 หนา6 | รูØ3.4×4 countersink90°ด้านนอก รูกลางØ14 รูลดน้ำหนักØ8×2; เจาะ/countersinkก่อนชุบแข็ง และถ่วงสมดุลร่วมดุม |
| Upright | ซ้าย1+ขวา1 / 6061-T6 หนา6 | รูแกนØ8.2; Ø2.5×4ต๊าปM3ทะลุ; ต๊าปM3ที่ขอบบน/ล่างเข้ารูbraceลึก8ตาม STEP; ซ้ายมี reliefมอเตอร์ด้านหลัง ใช้ไฟล์ซ้าย/ขวาแยก |
| Wedgelet | 2 mirror / เหล็กหนา2 | รูØ3.4×2 countersink90°ด้านบน ลับขอบหน้า ทำซ้าย/ขวาโดยอ้าง assembly |
| Brace บน | 1 / 6061 หนา3 | มีช่องหลบสายพานกลางใหม่; ใช้ DXF ของชิ้นบนโดยเฉพาะ |
| Brace ล่าง | 1 / 6061 หนา3 | รู4รูเหมือนแนวเดิม รูกลางใช้ nose skid หัวสกรูใต้ skidต้องเสมอผิว |
| แผ่นมอเตอร์อาวุธ | 1 / 6061 หนา3 | รูยึดตามมอเตอร์จริง + รูยึดPETGfeet2รู + reliefหลบมอเตอร์ขับหน้า; ไม่เจาะตามกากบาท16×19เก่าถ้ายังไม่ตรงของจริง |
| Skirt ข้าง/ท้าย | 2+1 / 5052หนา0.8 | รูØ2.2; ขยายเป็นร่องปรับสูงประมาณ1ตามแนวลาดก่อนประกอบ ลบคมทุกขอบ |

## ชิ้นกลึง

ส่ง STEP แยกชิ้นพร้อมรายละเอียดนี้ ไม่ตีความ STL เป็นแบบกลึง

- **Beater hub:** 6061 OD30 ยาว40 รูรับ608 nominalØ22ทะลุ ร่องสายพานกว้าง6 ลึก1.5 (รากØ27) ต๊าปM3×4ต่อปลาย วงPCD26 มุม45/135/225/315° ลึก8 ยืนยัน press fit กับลูกปืนจริงและร้านกลึงก่อนทำ ไม่กำหนดค่าพิกัดอัดจากค่าประมาณใน CADเพียงอย่างเดียว
- **Motor pulley R1:** 6061 OD30 ส่วนรอก x=−4…4 ยาว8 ร่องกว้าง6 ลึก1.5 รากØ27 เพิ่ม bossOD10ที่x=4…9ยาว5 รูกลางตามเพลาจริง nominalØ5 มีรูต๊าปM3รัศมีตาม STEPที่x=6เพื่อสกรูตัวหนอน ฝังแม่เหล็กØ3ลึก2ที่ด้านx=4สองรู ณระยะ7จากแกนตรงข้ามกัน ใช้แม่เหล็กกลับขั้วให้สมดุล รูต้องไม่ทะลุร่อง รอกกับดุมใช้รากØ27เท่ากันเพื่อ1:1
- **Spacers:** 6061 ID8.2/OD11 ยาว7สองตัว และ26หนึ่งตัว ลำดับระหว่างแผ่นตั้ง:7+608(7)+26+608(7)+7=54 ระหว่างหน้าด้านในแผ่นตั้ง; รวมแผ่นตั้ง6สองข้างเป็น66
- **แกนใบ:** สกรูM8เกรด12.9 ความยาวต้องรวม stack66+แหวน+เกลียวเต็มน็อตล็อก R1ใช้×80และจำลองหัว/แหวน/น็อตครบแล้ว มีช่องบล็อกขันØ21ในTPU ต้องยืนยันขนาดน็อตจริงก่อนล็อกการผลิต ไม่ใช้×70อัตโนมัติ
- **แกนบานพับ:** Ø3ยาว57 ร่องE-clipกว้าง0.6ถึงØ2.3 ณตำแหน่งปลายตามSTEP คู่กับDIN6799ขนาด2.3 ปลายด้านในเป็น stopกับแผ่นตั้ง

การประกอบเสร็จต้องยืนยัน: ลูกปืนไม่หมุนฟรีในดุม ชุดspacerล็อกวงในและโรเตอร์หมุนคล่อง โรเตอร์ไม่ถูแผ่นตั้ง และสกรูไม่ชนส่วนหมุน รายการนี้บันทึกใน `assembly.results` ก่อนปล่อยชุดผลิต

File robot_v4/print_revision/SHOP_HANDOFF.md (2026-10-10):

# ใบส่งงานร้านพิมพ์ — Robot V4 Print R1

**ขอราคาและพิมพ์ชิ้นทดลองก่อน ไม่ใช่ใบอนุมัติผลิตชุดใหญ่** ห้ามเปลี่ยนวัสดุ สเกล รูประกอบ หรือซ่อม mesh โดยไม่ส่งรายละเอียดกลับให้แก้ต้นฉบับ

## ข้อมูลที่ร้านต้องระบุ

| รายการ | คำตอบร้าน |
|---|---|
| ชื่อร้าน / ผู้รับงาน | รอยืนยัน |
| เครื่อง / พื้นที่พิมพ์ใช้ได้จริง XYZ | รอยืนยัน |
| หัวฉีด / ความกว้างเส้น / layer height | รอยืนยัน |
| Slicer / version / profile | รอยืนยัน |
| TPU 95A ยี่ห้อ/รุ่น และ PETG ยี่ห้อ/รุ่น | รอยืนยัน |
| Brim / support / วิธีเก็บงาน | รอยืนยัน |
| ราคาทดลอง รวมเก็บงาน/ส่ง | รอยืนยัน |
| ราคาชุดเต็ม รวมเก็บงาน/ส่ง | รอยืนยัน |
| น้ำหนักและเวลาพิมพ์แยกตาม STL | รอยืนยัน |

ถาดปัจจุบันประมาณ **190.5 × 217.3 × 54 มม.** ก่อน brim ฐานใช้ได้จริง 220 × 220 มม. ไม่พอสำหรับ brim 5 มม. โดยวางตรงตามแกน ให้เลือกเครื่องที่รองรับชิ้นเดียวรวม brim ที่ตกลง ห้ามตัดแบ่งตัวถังเพื่อแก้เรื่องฐานพิมพ์

## การตั้งค่าตั้งต้นสำหรับลองสไลซ์

ใช้หัวฉีด 0.4 มม. และ layer 0.2 มม. เป็นค่าประเมินเริ่มต้น ร้านต้องยืนยัน profile ตามวัสดุจริง

| กลุ่ม | วัสดุ | ตั้งต้น | ท่าที่ส่งออก / สิ่งต้องตรวจ |
|---|---|---|---|
| ถาดและฝา | TPU 95A | 4 walls, 60% gyroid | พื้นลงฐาน; ฝามีหลังคาโค้งและช่องสายพาน ต้องตรวจ support ถอดได้ |
| ยางล้อ | TPU 95A | 4 walls, เริ่มประเมิน 60% gyroid | หน้าวงแหวนลงฐาน ตรวจความยืดหยุ่นและ fit กับดุม |
| บานพับ/ดุม | PETG | 4 walls, ≥80% infill | รูแกนบล็อกเป็นแนวนอน; carrier/ดุมวางแกนหลักแนวตั้ง |
| ถาดแบต/แท่น/เสา/ฐานมอเตอร์ | PETG | 4 walls, เริ่ม 80% infill | ตรวจ slot สายรัด รูสกรู และช่องน็อต ไม่มีการลดเนื้อรอบรูบานพับต่ำกว่า 1.6 มม. |
| เสา Hall / collar | PETG | 4 walls, เริ่ม 80% infill | เสา Hall วางนอนใน STL ตรวจ support ที่ยื่นออก |

ชุดขนาด รู และจำนวนใช้ `output/manifest.json` ของ build ล่าสุด อย่าใช้คู่มือ V4 เดิมแทนรายการนี้ ไม่มีชิ้น mirror ให้ร้านสร้างเองแล้ว

## ผลที่ต้องส่งกลับ

- ไฟล์โครงการ slicer จริง เก็บ printer/material profile ท่าวางชิ้น support และจำนวนให้ครบ
- ภาพ layer preview ของบานพับ รู insert ช่องน็อตดุม ฝาหลังคาโค้ง และแนวสายพาน
- ตารางน้ำหนักและเวลาต่อ **หนึ่งชิ้นของแต่ละ STL** โปรแกรมคูณจำนวนเอง รวมข้อมูล support แยกออกจากมวลชิ้นที่จะอยู่บนรถ
- ใบเสนอราคาแยกชิ้นทดลอง/ชุดเต็ม วัสดุ งานเก็บผิว และส่ง ไม่ถือว่างบพิมพ์เส้นเดิม 550 บาทเป็นราคาจ้างร้าน
- ผลการทดลองตาม `FIT_TEST.md` และ SHA256 build ที่ใช้อยู่ หากเปลี่ยน profile/วัสดุ/ท่าพิมพ์ในจุดสวม ต้องลองจุดนั้นใหม่

เงื่อนไขงบ: รวมอะไหล่ โลหะ ชิ้นพิมพ์ทดลอง ชุดเต็ม และค่าส่งทั้งโครงการไม่เกิน **6,000 บาท** หากเกิน ให้รายงานก่อนผลิต ไม่มีคำสั่งซื้อหรือการอนุมัติสั่งผลิตในใบนี้

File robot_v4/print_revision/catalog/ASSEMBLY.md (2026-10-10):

**R2 จากข้อมูลเว็บ: ยังไม่วัดจริง/ไม่ปล่อยผลิต**

ESCใช้68×25×8mm; ตำแหน่งศูนย์XY: ESC(−22,−42.5),ESP32(0,−15.75),DRVซ้าย(−43,−15),DRVขวา(43,−15),IMU(42,−42.5) ขอบแท่นมีช่องออกสายESCซ้าย/ขวาและพื้นที่เดินสายด้านซ้าย ต้องเทียบการโค้งสาย14AWGจริงก่อนยืนยัน

Insertเปลี่ยนเป็นOD5ยาว4mm: รูเริ่มทดลอง4.6mm ฝาเปลี่ยนสกรูตั้งต้นเป็นM3×6; สกรูcarrier/wedgeletต้องตรวจว่าปลายไม่เกินเนื้อและแกนตามเกลียว4mmจริงก่อนซื้อ

# วิธีประกอบและรายการสกรู — V4 Print R2 ต้นแบบ

หน่วยมม. ใช้ไฟล์ R2 ทั้งชุด ห้ามปนถาด ฝา brace บน หรือรอกมอเตอร์ V4 เดิมกับ R2 ตำแหน่งเพลาหน้าและมอเตอร์อาวุธเปลี่ยนแล้ว ความยาวสกรูด้านล่างเป็นค่าตั้งต้น ต้องเทียบความลึกเกลียวและหัวสกรูจริงก่อนลงผลพร้อมประกอบใน JSON

## รายการสกรูและอุปกรณ์ยึด

| จุดยึด | จำนวน | ตั้งต้น | วิธีตรวจความยาว / งานต่อ |
|---|---:|---|---|
| มอเตอร์ขับ | 8 ตามรู nominal; ใช้จำนวนรูจริง | M3 button head ×8 + แหวน OD≤7 | ผนัง 4 มี recess ด้านล้อ 1; ผ่านพลาสติก 3 + แหวนราว 0.5 เหลือเข้าเกลียวราว 4.5 ต้องไม่ชนกลไกในเกียร์ |
| ดุมล้อ | 4 | น็อต M3 + สกรูตัวหนอน M3 ×22 | ช่องน็อตเปิดด้านข้าง; เลือกความยาวให้ปลายกดเพลาด้านแบนโดยหัวไม่ชนตัวถัง/ยาง ห้ามพิมพ์เกลียวพลาสติกแทนน็อต |
| แผ่นตั้งใบ | 8 | M3 ×20 + แหวน | ผ่านบล็อก TPU 16 เข้าต๊าปแผ่น 6061 ประมาณ 4 |
| จานอาวุธ | 8 | M3 หัวจม 90° ×10 | ผ่านเหล็ก 6 เข้าเกลียวดุมประมาณ 4; countersink จานจริง ไม่ใช่รูใน DXF อย่างเดียว |
| Brace เข้าแผ่นตั้ง | 4 | M3 ×10 | ผ่าน brace 3 เข้าต๊าปขอบ 7; รูต๊าปลึกอย่างน้อย 8 |
| Nose skid | 2 | M3 หัวจม ×8 + น็อตล็อก | แผ่น 3 + brace 3; เก็บหัวให้เสมอใต้ skid ห้ามต่ำกว่า skid |
| ฝา TPU | 6 | M3 button head ×6 + แหวน | ฝา 2 + แหวน 0.5 เข้า insert ประมาณ 3.5; ทดสอบไม่ดึง insert หลุด |
| บล็อกบานพับเข้าผนัง | 4 | M3 ×12 + แหวน | ผนัง 8 + แหวน 0.5 เข้า insert ประมาณ 3.5 |
| Wedgelet เข้า carrier | 4 | M3 หัวจม ×8 | แผ่นเหล็กแนวเอียงต้อง countersink; ตรวจว่าไม่ชนแกนบานพับ |
| แผ่นมอเตอร์อาวุธเข้า PETG feet | 2 | M3 ×10 + น็อต M3 ในช่อง | ผ่านแผ่น 3 เข้า foot; น็อตวางจากด้านที่แผ่นปิด ตรวจเกลียวเต็มน็อต |
| PETG feet เข้าพื้น TPU | 2 | M3 ×20 + แหวนสองด้าน + น็อตล็อก | พื้น 3 + foot 13 =16; หัวใต้พื้นต้องไม่ต่ำถึงสนาม |
| ถาดแบตเข้าพื้น | 4 | M3 ×10 + แหวนสองด้าน + น็อตล็อก | พื้น 3 + ถาด 1.6; ใช้แหวนเล็กไม่ชน slot/แบต |
| แท่นอุปกรณ์ผ่านเสารองเข้าพื้น | 4 | M3 ×40 + แหวนสองด้าน + น็อตล็อก | พื้น 3 + เสารอง 31.6 + แท่น 2 =36.6; ตรวจส่วนยื่นและพื้นที่ขันด้วยของจริง |
| Hall post | 1 | M2 ×8 + แหวน + น็อตล็อก | มีรูผ่าน PETG foot/pื้น; เสาอยู่ห่างจานรอกและสายพาน |
| Disconnect collar | 2 | M2 ×14 + แหวน + น็อตล็อก | ผนัง 8 + collar 3; ตรวจหัวน็อตไม่ติดล้อหรือสาย |
| Skirt | 11 | M2 เกลียวปล่อย ×8 | รูนำ Ø1.6 ใน TPU; ตรวจขันไม่รูด และปรับระดับแผ่นด้วยร่องบนโลหะ |
| แกนอาวุธ | 1 | M8 ×80 เกรด12.9 + แหวน/น็อตล็อก | เปรียบเทียบ stack 66 มม. แบบใหม่จำลองหัว/แหวน/น็อตครบและมีช่องบล็อกขัน Ø21; ต้องยืนยันขนาดและเกลียวจริง |
| แกน wedgelet | 2 | เหล็ก Ø3 ×57 + E-clip DIN6799 2.3 | ร่องกว้าง0.6 ลึกถึงØ2.3 ตำแหน่งปลายตาม STEP; ไม่ตัดแกนเองโดยไม่มีร่องกันหลุด |
| Insert M3 | 14 | Friend Robot M3×4×5: OD5 ยาว4 (รอวัด) | ฝา6, รางบล็อก4, carrier4; ไม่ใช่ insert wedgelet ในบล็อกเก่า |
| แบต/บอร์ด | 2 สายรัดแบต + 2 cable ties ต่อโมดูล5ตัว | สายรัดกว้าง≤10, ties ผ่านช่อง3.6 | รัดได้โดยไม่กดขั้วต่อหรือบีบแบต บอร์ดมีฉนวน/โฟม1มม. |

จำนวนเดิมอาจเปลี่ยนเมื่อมอเตอร์จริงมีรูต่างจาก nominal ใช้ตำแหน่งรูจาก STEP ของ build สุดท้ายเป็นหลัก ราคารวมต้องรวมรายการ R2 เพิ่มเหล่านี้

## ลำดับประกอบ

1. ทำชิ้นโลหะและเก็บคมตาม `MACHINING.md` ลองลูกปืนกับดุมจริงก่อนประกอบโรเตอร์ เก็บรอยกระแทกและรอยแตกของชิ้นพิมพ์ทดลอง
2. ฝัง insert ในฝาถาด รางบานพับ และ carrier ลองขันตาม FIT_TEST ก่อนประกอบชุดใหญ่
3. ใส่มอเตอร์ขับ ขันสกรูจากฝั่งล้อให้หัวและแหวนอยู่ใน recess ตรวจ gap ระหว่างหัวสกรูกับดุม ล็อกดุมบนด้านแบนและสวมยาง
4. ยึด PETG feet และแผ่นมอเตอร์อาวุธ โดยใส่น็อตเข้าช่องก่อนปิดด้วยแผ่นมอเตอร์ ขันมอเตอร์ตามรูจริง ลองสายพานและจุดที่ผ่าน bulkhead/ฝา/brace บน
5. ขันแผ่นตั้งและ brace ตามแบบใหม่ ใส่ spacer7–608–spacer26–608–spacer7 แล้วขันแกนตายให้แน่น โรเตอร์ต้องหมุนคล่องและไม่เลื่อนจนถูกแผ่นตั้ง ตรวจหัวสกรูจานไม่โดนชิ้นอื่น
6. ยึด nose skid หัวสกรูเสมอใต้ผิว ตั้ง skid สูงจากสนาม1มม. และ skirt0.5มม. รู skirt โลหะยังต้องขยายเป็นร่องตามคู่มือโลหะ
7. ประกอบบล็อก/carrier/แผ่น wedgelet และใส่แกน/E-clip ทั้งสองข้าง ตรวจลงพื้นเองและยกไม่ติด ความหนา knuckle/วงรับแกน carrier ของ R2เพิ่มแล้ว
8. ยึดถาดแบต ร้อยสายรัดก่อนวางแบต ยึดแท่นอุปกรณ์บนเสารองด้วยน็อตผ่านพื้น หัวน็อตใต้ถาดต้องไม่ต่ำถึงพื้นสนาม4มม. บอร์ดใช้ฉนวน/โฟม1มม.และ cable ties ผ่าน slot จัดหัวปลั๊กไว้ตาม connector keep-out ที่วัด
9. ยึด Hall post และ collar หันด้านแบน sensor เข้ารอก ใส่แม่เหล็กสองรูโดยกลับขั้วกัน ให้ sensorอยู่ห่างหน้ารอก2.5มม.ตามแบบ ทดลองตรวจจับด้วยมือก่อนติดกาว
10. เดินสายให้ไม่ผ่านช่องล้อ/สายพาน/วงหมุนใบและไม่ถูกฝาหนีบ ยึดสายด้วย ties บนแท่น ตรวจถอด link ได้จากภายนอก และถอดฝาได้โดยไม่ดึงสาย
11. ตรวจตัวถังและชุดประกอบแบบไม่เปิดอาวุธ ชั่งน้ำหนักรวมและโหลดเพลาหน้า/หลัง บันทึกหลักฐาน งานทดสอบไฟ เฟิร์มแวร์ และชนจริงยังเป็นงานถัดไป

## จุดที่ต้องวัดก่อนยืนยันความพร้อม

- ความยาวแกน M8 ต้องมีเกลียวเต็มน็อตล็อก หลังรวม stack และแหวน R2 เลือก M8×80 และเพิ่มช่องใส่บล็อกขัน Ø21 ใน TPU แล้ว ให้ยืนยันเกลียวกับน็อตจริง; ข้อมูลนี้ต้องถูกล็อกในแบบก่อน release
- มอเตอร์/เพลา/น็อตต้องตรงกับ inputs; ถ้า head/washer ที่ซื้อใหญ่กว่า recess ให้แก้ CAD ก่อนพิมพ์ ไม่เจาะหน้างานโดยไม่บันทึก
- ทดลองนำเครื่องมือเข้าทุกจุด โดยเฉพาะสกรูมอเตอร์หน้าหลัง แท่นอุปกรณ์ และสกรูฐานมอเตอร์อาวุธ ตรวจขั้วต่อจริงกับ keep-out
- น้ำหนักชิ้นพิมพ์จาก slicer เป็นประมาณการ ก่อนใช้งานต้องชั่งหุ่นจริงไม่เกิน2กก. และโหลดล้อหลังไม่น้อยกว่า10%

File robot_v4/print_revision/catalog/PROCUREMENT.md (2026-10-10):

# รายการจัดหาและงบบางส่วน — Robot V4 Print R2

ข้อมูลเว็บวันที่ 2026-10-08; ผู้ใช้ยังไม่ได้ซื้ออะไหล่ ไม่มีคำสั่งซื้อหรือใบเสนอราคาที่ร้านยืนยัน

**ยอดราคาที่พบ 2,268 บาท; เพดานที่เหลือ 3,732 บาท** ยอดนี้ยังไม่ใช่ราคาทั้งโครงการ รายการรอราคาไม่ถูกนับเป็นศูนย์ และไม่ถือว่างบผ่าน

| รายการ | จำนวนใช้ / หน่วยขาย | ยอดเว็บ (บาท) | แหล่ง / สิ่งต้องยืนยัน |
|---|---:|---:|---|
| มอเตอร์ขับ DCM068 | 4 / 1 ต่อหน่วยขาย | 760 | [TH01](https://www.fromfactory.net/product/6096/ดีซีมอเตอร์-พร้อมเกียร์ทด-jga25-370-gear-dc-motor-12v-high-torque-5-10-30-60-400-rpm-ขนาด-25mm); ราคา190ต่อมอเตอร์; ต้องยืนยันstockครบ4และdrawing |
| มอเตอร์อาวุธ DYS D3536 1250KV | 1 / 1 ต่อหน่วยขาย | รอราคา | รอรุ่น/ราคา; รอร้านไทย/SKU/drawing; ALT02เป็นทางเลือกยังไม่เลือก |
| Skywalker40A V2 PN80060140 | 1 / 1 ต่อหน่วยขาย | 490 | [TH03](https://www.abcflying.com/product/8569/hobbywing-skywalker-40a-v2-ubec-3s-4s); ยืนยันstockและความเข้ากันกับมอเตอร์อาวุธ |
| DOGCOM3S850150C UCELL SKU-08923 | 1 / 1 ต่อหน่วยขาย | 490 | [TH07](https://www.fpvonly.com/product/dogcom-3s-450-550-560-650-850-1050mah-150c-lipo-battery-อุปกรณ์โดรน-drone/11000371400006958); เว็บ490/คงเหลือ9; รอขนาดมวล/ฉลาก/stockก่อนซื้อ |
| ESP32 30pin Type-C CH340C | 1 / 1 ต่อหน่วยขาย | 180 | [TH04](https://www.mikroelec.com/product/2990/esp32-30pin-type-c-ch340c-esp-wroom-32-board); ผู้ใช้ยังไม่มีบอร์ด; รอความสูงหลังต่อสาย |
| DRV8871 ModuleMore SKU01477 | 2 / 1 ต่อหน่วยขาย | 150 | [TH05](https://www.modulemore.com/product/1477/บอร์ดขับมอเตอร์-drv8871-3-6a-motor-driver-dc-h-bridge-pwm-driver-module); 2บอร์ด; ต้องตรวจcurrent-limitกับ2มอเตอร์ต่อช่อง |
| GY-521 MPU6050 | 1 / 1 ต่อหน่วยขาย | 80 | [TH06](https://www.cybertice.com/product/40/gy-521-mpu6050-6-axis-imu-module-โมดูลวัดความเร่งและไจโรสโคป-3-แกน); รอความสูง/ขาต่อและมวล |
| A3144 IC | 1 / 1 ต่อหน่วยขาย | 10 | [TH10](https://www.allnewstep.com/product/351/a3144-a3144e-oh3144e-hall-effect-sensor); IC ไม่ใช่module; รวมขา/ฉนวนด้วย |
| DS18B20 TO92 | 2 / 1 ต่อหน่วยขาย | 50 | [TH11](https://www.arduitronics.com/product/383/ds18b20-temperature-sensor); 2ตัวตามแบบ |
| M3x4x5 inserts (10pcs/ถุง) | 14 / 10 ต่อหน่วยขาย | 40 | [TH09](https://www.friendrobotshop.com/product/385/m3x4x5-insert-nut-สำหรับงานพิมพ์-3d-สำหรับน๊อต-m3-สูง-4-มม-ขนาดเส้นผ่านศูนย์กลาง-5-มม-10-ชิ้น); ต้องซื้อ2ถุง รวม40บาท; trialfitยังไม่ผ่าน |
| SRT608ZZ 8x22x7 | 2 / 1 ต่อหน่วยขาย | 18 | [TH08](https://sunrise.co.th/en/product/deep-groove-ball-bearings-8x22x7-abec-1-jis-b1514-class-0); 2ตลับ; รอmass/stock |
| จอยBluetooth | 1 / 1 ต่อหน่วยขาย | รอราคา | รอรุ่น/ราคา; รอmodelที่จับคู่Bluepad32ได้จริง ไม่ถือว่าcloneทุกรุ่นใช้ได้ |
| เครื่องชาร์จ+แหล่งจ่าย+สายแปลง | 1 / 1 ต่อหน่วยขาย | รอราคา | รอรุ่น/ราคา; รอรุ่นที่balance-charge3Sพร้อมอุปกรณ์ครบ |
| ตัวตัดไฟ+ฟิวส์+holder | 1 / 1 ต่อหน่วยขาย | รอราคา | รอรุ่น/ราคา; รอขนาด/พิกัดกระแสจริง |
| สายไฟ+XT30+สายสัญญาณ+R | 1 / 1 ต่อหน่วยขาย | รอราคา | รอรุ่น/ราคา; รวม3คู่XT30และฉนวน; TH18ยังไม่แยกvariant |
| แม่เหล็ก3x2mmสองลูก | 1 / 1 ต่อหน่วยขาย | รอราคา | รอรุ่น/ราคา; TH12รอราคาตัวเลือก |
| สายรัดแบตสองเส้น+ties | 1 / 1 ต่อหน่วยขาย | รอราคา | รอรุ่น/ราคา; ต้องผ่านslot10mmและรอบแบตจริง |
| สายพานกลมPU5mmเชื่อมวง | 1 / 1 ต่อหน่วยขาย | รอราคา | รอรุ่น/ราคา; รอราคาความยาวขั้นต่ำ/เชื่อม/ทดลอง |
| สกรู/น็อต/แหวน/สำรองยกเว้นinsert | 1 / 1 ต่อหน่วยขาย | รอราคา | รอรุ่น/ราคา; ตามASSEMBLY.md ไม่รวมinsertซ้ำ |
| M8x80hex12.9+น็อตล็อก+แหวน | 1 / 1 ต่อหน่วยขาย | รอราคา | รอรุ่น/ราคา; TH14รอแบ่งขายและเกลียวตรงแบบ |
| แกนบานพับ3x57สองแกน+Eclips | 1 / 1 ต่อหน่วยขาย | รอราคา | รอรุ่น/ราคา; ร่องตามSTEP รอร้านกลึงเสนอราคา |
| UHMW3mm skid | 1 / 1 ต่อหน่วยขาย | รอราคา | รอรุ่น/ราคา; ตัด/countersinkตามMACHINING |
| แผ่นโลหะตัด9แบบ | 1 / 1 ต่อหน่วยขาย | รอราคา | รอรุ่น/ราคา; แยกวัสดุ/จำนวนตามmanifestและMACHINING |
| งานกลึงรอก/ดุม/spacers/ต๊าป/เก็บคม | 1 / 1 ต่อหน่วยขาย | รอราคา | รอรุ่น/ราคา; รวมcountersink/ร่อง/งานประกอบที่ระบุ |
| พิมพ์ชิ้นทดลอง+เก็บงาน | 1 / 1 ต่อหน่วยขาย | รอราคา | รอรุ่น/ราคา; เลือกcouponและชิ้นสวมที่ต้องใช้ ไม่จำเป็นต้องพิมพ์38ไฟล์ทั้งหมด |
| พิมพ์TPU95A/PETGชุดเต็ม+support/เก็บงาน | 1 / 1 ต่อหน่วยขาย | รอราคา | รอรุ่น/ราคา; 26ชิ้น17แบบตามmanifest; ชิ้นใหญ่ยังไม่อนุมัติ |
| ค่าส่ง/ภาษีที่ยังไม่รวม | 1 / 1 ต่อหน่วยขาย | รอราคา | รอรุ่น/ราคา; อย่านับซ้ำส่วนที่รวมในใบเสนอราคา |
| เงินเผื่อ | 1 / 1 ต่อหน่วยขาย | รอราคา | รอรุ่น/ราคา; ต้องระบุจำนวนไม่ปล่อยว่างก่อนสรุปงบ |

## ลำดับปิดข้อมูล

1. ขอข้อมูลมอเตอร์ขับครบ 4 ตัว มอเตอร์อาวุธ แบต และบอร์ดขับก่อนซื้อชิ้นที่ยึดกับ CAD; ใช้ข้อความใน SUPPLIER_REQUESTS.md
2. ขอราคางานกลึง/ตัดโลหะ ชิ้นทดลอง และชุดพิมพ์เต็มจากไฟล์ DRAFT revision เดียวกันก่อนสั่งงาน รวม support เก็บงาน ภาษีและส่ง
3. ล็อก SKU และรับของมาวัด กรอก actual/evidence ใน inputs_R2.json แล้วสร้าง revision ใหม่; ค่าจากเว็บไม่ใช่ actual
4. พิมพ์เฉพาะชิ้นทดลองที่ได้รับอนุมัติและใช้ profile เดียวกับชุดเต็ม บันทึกผลตาม FIT_TEST.md; หาก layout เปลี่ยนใช้ชุดทดลองจาก build ใหม่
5. ปิด slicer/มวล/โหลดล้อหลัง/ราคาและงานประกอบทุกข้อก่อนปล่อยชุดใหญ่

ราคาสกรูใช้ BOM ใน ASSEMBLY.md และต้องรวมแหวน น็อตล็อก น็อตฝัง สำรอง และ insert 14 จุด (ซื้อ 2 ถุง ถุงละ 10 ตัว)
ตัวเลือก SURPASS C3536 V2 1300KV จาก UDSHOBBY ยังเป็นทางเลือกแยก ไม่ใช้ราคา 840 บาทเติมยอดของ DYS 1250KV และไม่เปลี่ยนเพลา/รอก/ESC โดยไม่มีข้อมูลตรงรุ่น
CAD R2 ยังประมาณ 1,969.91 กรัม; ต้องลดหรือยืนยันมวลให้ถึงเป้า 1,900 กรัม และตรวจขั้นต่ำไม่เกิน 2,000 กรัมด้วยมวล slicer+อะไหล่จริง
จอยและเครื่องชาร์จเป็นต้นทุนโครงการ แม้ไม่อยู่บนตัวหุ่น ไม่สมมติว่าเป็นของที่มีแล้ว

สร้างรายงานซ้ำ: `.venv-v4-print/bin/python robot_v4/print_revision/procurement.py` จาก root ของ repository

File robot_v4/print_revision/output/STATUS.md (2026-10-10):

# V4 Print R1 — DRAFT / ยังไม่ปล่อยผลิต

ไฟล์ชุดนี้มีค่าขนาดต้นแบบที่ยังไม่วัดจริง ห้ามส่งพิมพ์ชุดใหญ่จากสถานะนี้

Build SHA256: `1e42935da45872f495cb320ad9d2b20902f84db99dab7fda7827dc19a410a759`

CAD ผ่าน: True · mesh ผ่าน: True
มวลประมาณ: 1966.16 g · โหลดล้อหลังประมาณ: 10.5%
MuJoCo ผ่าน: True · โหลดล้อหลังจำลอง: 12.4% · ระยะฟันต่ำสุดตอนเร่งใบ: 2.08 mm

## งานที่ต้องยืนยันก่อนปล่อยชุดผลิต

- มวลประมาณยังเกินเป้าหมาย 1900 g; เหลือเผื่อถึง 2000 g เพียง 33.84 g ต้องแทนด้วยน้ำหนัก slicer และอะไหล่จริงก่อนตัดสินใจ
- โหลดล้อหลังเชิงสถิตผ่านขั้นต่ำ 10% แต่ยังไม่ถึงเป้าหมาย 15%
- Unconfirmed hardware: drive_Front_L
- Unconfirmed hardware: drive_Front_R
- Unconfirmed hardware: drive_Rear_L
- Unconfirmed hardware: drive_Rear_R
- Unconfirmed hardware: weapon_motor
- Unconfirmed hardware: battery
- Unconfirmed hardware: esc
- Unconfirmed hardware: esp32
- Unconfirmed hardware: drv_left
- Unconfirmed hardware: drv_right
- Unconfirmed hardware: imu
- Unconfirmed hardware: disconnect
- Unconfirmed hardware: bearing_608
- Unconfirmed hardware: hinge_pin
- Unconfirmed hardware: insert_m3
- Unconfirmed hardware: nut_m3
- Unconfirmed hardware: hall_sensor
- Unconfirmed hardware: dead_shaft
- Unconfirmed hardware: clips
- Unconfirmed hardware: belt
- Unconfirmed hardware: skid
- Unconfirmed hardware: rotor_screws
- Unconfirmed hardware: baseline_fasteners
- Unconfirmed hardware: revision_fasteners
- Unconfirmed hardware: wiring
- Unconfirmed hardware: aux_sensors
- Unconfirmed hardware: straps
- Missing/current-build failed evidence: fit
- Missing/current-build failed evidence: assembly
- Calibrated fit dimensions missing
- Shop/printer/material profile unconfirmed
- Usable build volume/brim missing or invalid
- Slicer project/review/masses missing or stale
- Complete confirmed project cost missing

## ชิ้นพิมพ์ต้นแบบ

| ไฟล์ | วัสดุ | จำนวน | ขนาด XYZ มม. |
|---|---|---:|---|
| V4_R1_Tub_TPU.stl | TPU95A | 1 | 190.523 × 217.261 × 54.001 |
| V4_R1_Lid_TPU_2mm.stl | TPU95A | 1 | 176.0 × 174.004 × 5.005 |
| V4_R1_Wedgelet_Block_PETG_L.stl | PETG | 1 | 54.0 × 41.2 × 14.0 |
| V4_R1_Wedgelet_Carrier_PETG_L1.stl | PETG | 1 | 12.5 × 15.2 × 20.0 |
| V4_R1_Wedgelet_Carrier_PETG_L2.stl | PETG | 1 | 12.5 × 15.2 × 16.0 |
| V4_R1_Wedgelet_Block_PETG_R.stl | PETG | 1 | 54.0 × 41.2 × 14.0 |
| V4_R1_Wedgelet_Carrier_PETG_R1.stl | PETG | 1 | 12.5 × 15.2 × 20.0 |
| V4_R1_Wedgelet_Carrier_PETG_R2.stl | PETG | 1 | 12.5 × 15.2 × 16.0 |
| V4_R1_Wheel_Hub_PETG.stl | PETG | 4 | 44.003 × 44.003 × 16.003 |
| V4_R1_Wheel_Tyre_TPU95A.stl | TPU95A | 4 | 64.005 × 64.005 × 16.005 |
| V4_R1_Hall_Post_PETG.stl | PETG | 1 | 46.5 × 16.0 × 10.0 |
| V4_R1_Weapon_Mount_Foot_PETG_1.stl | PETG | 1 | 8.0 × 13.0 × 13.0 |
| V4_R1_Weapon_Mount_Foot_PETG_2.stl | PETG | 1 | 8.0 × 11.0 × 13.0 |
| V4_R1_Battery_Tray_PETG.stl | PETG | 1 | 83.001 × 38.0 × 5.001 |
| V4_R1_Electronics_Platform_PETG.stl | PETG | 1 | 122.0 × 53.0 × 4.001 |
| V4_R1_Electronics_Standoff_PETG.stl | PETG | 4 | 8.001 × 8.001 × 31.601 |
| V4_R1_Disconnect_Collar_PETG.stl | PETG | 1 | 3.0 × 16.0 × 16.0 |

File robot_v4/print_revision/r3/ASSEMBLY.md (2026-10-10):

**R3 จากข้อมูลเว็บ: ยังไม่วัดจริง/ไม่ปล่อยผลิต**

ESCใช้68×25×8mm; ตำแหน่งศูนย์XY: ESC(−22,−42.5),ESP32(0,−15.75),DRVซ้าย(−43,−15),DRVขวา(43,−15),IMU(42,−42.5) ขอบแท่นมีช่องออกสายESCซ้าย/ขวาและพื้นที่เดินสายด้านซ้าย ต้องเทียบการโค้งสาย14AWGจริงก่อนยืนยัน

Insertเปลี่ยนเป็นOD5ยาว4mm: รูเริ่มทดลอง4.6mm ฝาเปลี่ยนสกรูตั้งต้นเป็นM3×6; สกรูcarrier/wedgeletต้องตรวจว่าปลายไม่เกินเนื้อและแกนตามเกลียว4mmจริงก่อนซื้อ

# วิธีประกอบและรายการสกรู — V4 Print R3 ต้นแบบ

หน่วยมม. ใช้ไฟล์ R3 ทั้งชุด ห้ามปนถาด ฝา brace บน หรือรอกมอเตอร์ V4 เดิมกับ R3 ตำแหน่งเพลาหน้าและมอเตอร์อาวุธเปลี่ยนแล้ว ความยาวสกรูด้านล่างเป็นค่าตั้งต้น ต้องเทียบความลึกเกลียวและหัวสกรูจริงก่อนลงผลพร้อมประกอบใน JSON

## รายการสกรูและอุปกรณ์ยึด

| จุดยึด | จำนวน | ตั้งต้น | วิธีตรวจความยาว / งานต่อ |
|---|---:|---|---|
| มอเตอร์ขับ | 8 ตามรู nominal; ใช้จำนวนรูจริง | M3 button head ×8 + แหวน OD≤7 | ผนัง 4 มี recess ด้านล้อ 1; ผ่านพลาสติก 3 + แหวนราว 0.5 เหลือเข้าเกลียวราว 4.5 ต้องไม่ชนกลไกในเกียร์ |
| ดุมล้อ | 4 | น็อต M3 + สกรูตัวหนอน M3 ×22 | ช่องน็อตเปิดด้านข้าง; เลือกความยาวให้ปลายกดเพลาด้านแบนโดยหัวไม่ชนตัวถัง/ยาง ห้ามพิมพ์เกลียวพลาสติกแทนน็อต |
| แผ่นตั้งใบ | 8 | M3 ×20 + แหวน | ผ่านบล็อก TPU 16 เข้าต๊าปแผ่น 6061 ประมาณ 4 |
| จานอาวุธ | 8 | M3 หัวจม 90° ×10 | ผ่านเหล็ก 6 เข้าเกลียวดุมประมาณ 4; countersink จานจริง ไม่ใช่รูใน DXF อย่างเดียว |
| Brace เข้าแผ่นตั้ง | 4 | M3 ×10 | ผ่าน brace 3 เข้าต๊าปขอบ 7; รูต๊าปลึกอย่างน้อย 8 |
| Nose skid | 2 | M3 หัวจม ×8 + น็อตล็อก | แผ่น 3 + brace 3; เก็บหัวให้เสมอใต้ skid ห้ามต่ำกว่า skid |
| ฝา TPU | 6 | M3 button head ×6 + แหวน | ฝา 2 + แหวน 0.5 เข้า insert ประมาณ 3.5; ทดสอบไม่ดึง insert หลุด |
| บล็อกบานพับเข้าผนัง | 4 | M3 ×12 + แหวน | ผนัง 8 + แหวน 0.5 เข้า insert ประมาณ 3.5 |
| Wedgelet เข้า carrier | 4 | M3 หัวจม ×8 | แผ่นเหล็กแนวเอียงต้อง countersink; ตรวจว่าไม่ชนแกนบานพับ |
| แผ่นมอเตอร์อาวุธเข้า PETG feet | 2 | M3 ×10 + น็อต M3 ในช่อง | ผ่านแผ่น 3 เข้า foot; น็อตวางจากด้านที่แผ่นปิด ตรวจเกลียวเต็มน็อต |
| PETG feet เข้าพื้น TPU | 2 | M3 ×20 + แหวนสองด้าน + น็อตล็อก | พื้น 3 + foot 13 =16; หัวใต้พื้นต้องไม่ต่ำถึงสนาม |
| ถาดแบตเข้าพื้น | 4 | M3 ×10 + แหวนสองด้าน + น็อตล็อก | พื้น 3 + ถาด 1.6; ใช้แหวนเล็กไม่ชน slot/แบต |
| แท่นอุปกรณ์ผ่านเสารองเข้าพื้น | 4 | M3 ×40 + แหวนสองด้าน + น็อตล็อก | พื้น 3 + เสารอง 31.6 + แท่น 2 =36.6; ตรวจส่วนยื่นและพื้นที่ขันด้วยของจริง |
| Hall post | 1 | M2 ×8 + แหวน + น็อตล็อก | มีรูผ่าน PETG foot/pื้น; เสาอยู่ห่างจานรอกและสายพาน |
| Disconnect collar | 2 | M2 ×14 + แหวน + น็อตล็อก | ผนัง 8 + collar 3; ตรวจหัวน็อตไม่ติดล้อหรือสาย |
| Skirt | 11 | M2 เกลียวปล่อย ×8 | รูนำ Ø1.6 ใน TPU; ตรวจขันไม่รูด และปรับระดับแผ่นด้วยร่องบนโลหะ |
| แกนอาวุธ | 1 | M8 ×80 เกรด12.9 + แหวน/น็อตล็อก | เปรียบเทียบ stack 66 มม. แบบใหม่จำลองหัว/แหวน/น็อตครบและมีช่องบล็อกขัน Ø21; ต้องยืนยันขนาดและเกลียวจริง |
| แกน wedgelet | 2 | เหล็ก Ø3 ×57 + E-clip DIN6799 2.3 | ร่องกว้าง0.6 ลึกถึงØ2.3 ตำแหน่งปลายตาม STEP; ไม่ตัดแกนเองโดยไม่มีร่องกันหลุด |
| Insert M3 | 14 | Friend Robot M3×4×5: OD5 ยาว4 (รอวัด) | ฝา6, รางบล็อก4, carrier4; ไม่ใช่ insert wedgelet ในบล็อกเก่า |
| แบต/บอร์ด | 2 สายรัดแบต + 2 cable ties ต่อโมดูล5ตัว | สายรัดกว้าง≤10, ties ผ่านช่อง3.6 | รัดได้โดยไม่กดขั้วต่อหรือบีบแบต บอร์ดมีฉนวน/โฟม1มม. |

จำนวนเดิมอาจเปลี่ยนเมื่อมอเตอร์จริงมีรูต่างจาก nominal ใช้ตำแหน่งรูจาก STEP ของ build สุดท้ายเป็นหลัก ราคารวมต้องรวมรายการ R3 เพิ่มเหล่านี้

## ลำดับประกอบ

1. ทำชิ้นโลหะและเก็บคมตาม `MACHINING.md` ลองลูกปืนกับดุมจริงก่อนประกอบโรเตอร์ เก็บรอยกระแทกและรอยแตกของชิ้นพิมพ์ทดลอง
2. ฝัง insert ในฝาถาด รางบานพับ และ carrier ลองขันตาม FIT_TEST ก่อนประกอบชุดใหญ่
3. ใส่มอเตอร์ขับ ขันสกรูจากฝั่งล้อให้หัวและแหวนอยู่ใน recess ตรวจ gap ระหว่างหัวสกรูกับดุม ล็อกดุมบนด้านแบนและสวมยาง
4. ยึด PETG feet และแผ่นมอเตอร์อาวุธ โดยใส่น็อตเข้าช่องก่อนปิดด้วยแผ่นมอเตอร์ ขันมอเตอร์ตามรูจริง ลองสายพานและจุดที่ผ่าน bulkhead/ฝา/brace บน
5. ขันแผ่นตั้งและ brace ตามแบบใหม่ ใส่ spacer7–608–spacer26–608–spacer7 แล้วขันแกนตายให้แน่น โรเตอร์ต้องหมุนคล่องและไม่เลื่อนจนถูกแผ่นตั้ง ตรวจหัวสกรูจานไม่โดนชิ้นอื่น
6. ยึด nose skid หัวสกรูเสมอใต้ผิว ตั้ง skid สูงจากสนาม1มม. และ skirt0.5มม. รู skirt โลหะยังต้องขยายเป็นร่องตามคู่มือโลหะ
7. ประกอบบล็อก/carrier/แผ่น wedgelet และใส่แกน/E-clip ทั้งสองข้าง ตรวจลงพื้นเองและยกไม่ติด ความหนา knuckle/วงรับแกน carrier ของ R3เพิ่มแล้ว
8. ยึดถาดแบต ร้อยสายรัดก่อนวางแบต ยึดแท่นอุปกรณ์บนเสารองด้วยน็อตผ่านพื้น หัวน็อตใต้ถาดต้องไม่ต่ำถึงพื้นสนาม4มม. บอร์ดใช้ฉนวน/โฟม1มม.และ cable ties ผ่าน slot จัดหัวปลั๊กไว้ตาม connector keep-out ที่วัด
9. ยึด Hall post และ collar หันด้านแบน sensor เข้ารอก ใส่แม่เหล็กสองรูโดยกลับขั้วกัน ให้ sensorอยู่ห่างหน้ารอก2.5มม.ตามแบบ ทดลองตรวจจับด้วยมือก่อนติดกาว
10. เดินสายให้ไม่ผ่านช่องล้อ/สายพาน/วงหมุนใบและไม่ถูกฝาหนีบ ยึดสายด้วย ties บนแท่น ตรวจถอด link ได้จากภายนอก และถอดฝาได้โดยไม่ดึงสาย
11. ตรวจตัวถังและชุดประกอบแบบไม่เปิดอาวุธ ชั่งน้ำหนักรวมและโหลดเพลาหน้า/หลัง บันทึกหลักฐาน งานทดสอบไฟ เฟิร์มแวร์ และชนจริงยังเป็นงานถัดไป

## จุดที่ต้องวัดก่อนยืนยันความพร้อม

- ความยาวแกน M8 ต้องมีเกลียวเต็มน็อตล็อก หลังรวม stack และแหวน R3 เลือก M8×80 และเพิ่มช่องใส่บล็อกขัน Ø21 ใน TPU แล้ว ให้ยืนยันเกลียวกับน็อตจริง; ข้อมูลนี้ต้องถูกล็อกในแบบก่อน release
- มอเตอร์/เพลา/น็อตต้องตรงกับ inputs; ถ้า head/washer ที่ซื้อใหญ่กว่า recess ให้แก้ CAD ก่อนพิมพ์ ไม่เจาะหน้างานโดยไม่บันทึก
- ทดลองนำเครื่องมือเข้าทุกจุด โดยเฉพาะสกรูมอเตอร์หน้าหลัง แท่นอุปกรณ์ และสกรูฐานมอเตอร์อาวุธ ตรวจขั้วต่อจริงกับ keep-out
- น้ำหนักชิ้นพิมพ์จาก slicer เป็นประมาณการ ก่อนใช้งานต้องชั่งหุ่นจริงไม่เกิน2กก. และโหลดล้อหลังไม่น้อยกว่า10%

## R3: แยกการตรวจล่วงหน้ากับประกอบจริง

ก่อนปล่อยพิมพ์ ใช้preflightตรวจความยาวสกรู/thread depth/เครื่องมือเข้าถึงจากCADและtrial บันทึกbattery strapsสองจุด wire route/cutoff/โลหะตรงแบบและคู่มือครบ ห้ามกรอกassemblyจากผลcoupon

หลังประกอบเต็ม ผู้ใช้ตรวจทุกassembly/resultsตามinputs_R3 ถ่ายหลักฐานแบตแน่น/boardฉนวน/สายพ้นล้อ belt rotor/rotorหมุนคล่อง/ฝาเปิดซ่อม/เครื่องมือขันถึง/no undocumented drilling แล้วชั่งรวมและวัดโหลดล้อหลัง ลงmeasured_total_mass_gกับmeasured_rear_load_fraction นำผลตรวจไปreadiness.pyแยกจากPRINT_READY ถ้ายังต้องเจาะ/แต่งรูนอกคู่มือให้แก้แบบ/ระบุขั้นตอนและตรวจซ้ำก่อนรับรองประกอบ

แบต R3 เป็นผู้สมัครGNB8503S80A ขนาดเว็บ63×30×24mm ไม่ใช่ขนาดDOGCOMหรือ75×35×25nominalเก่า ถ้าย้ายไปชุดสำรอง ให้สร้างถาดใหม่ตามของจริงและทวนwire/strap/interference

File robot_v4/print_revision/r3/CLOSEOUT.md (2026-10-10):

# ปิด Robot V4 R3 — งานที่ทำได้และงานรอของจริง

| ขั้น | ผู้ทำ | ผลส่งมอบ / ผ่านเมื่อ | สถานะ |
|---|---|---|---|
| อะไหล่หลัก/สำรอง | ผมค้น; ผู้ใช้ประสาน | SKUครบ exact stock/price/ไฟฟ้า/ขนาดและมวล; ไม่มีรายการไม่ทราบ | เว็บปิดSURPASSรุ่นย่อย/คู่มือ GNBราคาไทย และJB361/MDD3Aทางเลือกเพิ่มแล้ว; ยังล็อกทั้งระบบไม่ได้ |
| ราคาอย่างน้อยพิมพ์2+โลหะ2 | ผมเตรียม; ผู้ใช้ส่งร้าน | quoteบริการครบ ทุกหมวดรวม300<=6000 | RFQ4ฉบับพร้อมส่ง ยังไม่มีquote |
| วัดและแก้แบบ | ร้านวัด; ผมปรับ | ภาพฉลาก/caliper/scale/ขาสายและเครื่องมือ; actual27กลุ่ม | R3ปรับแบต+SURPASSตามข้อมูลเว็บเป็นDRAFT; actual27กลุ่มรอวัดชิ้นที่จะได้รับ |
| มวล/สมดุล | ผมคำนวณ; ร้านslice | target1900/15%; hard2000/10%; ผลใหม่ทุกbuild | ยังพลาดเป้าหมาย ห้ามถือbatterymoveแก้สำเร็จ |
| ทดลองรอบ1→2 | ร้าน; ผมสร้างตามค่าที่เลือก | 0.1mmcoupon→ดุมยาง/hinge/carrier/lidจริง,4shafts,5cycles,profile+ภาพ/วิดีโอ | ไม่มีผลจริง |
| CAD/STL/โลหะ/จำลอง | ผม | BREP/sweep+1mm/wedge−2..14° mesh closed/manifold Z0 L/R และstatic/spin/turn/inverted | ผลร่างในoutput_R3 ยังใช้nominal |
| slicer | ร้าน | ทุกpartจำนวนวัสดุ/profile/support/brim และน้ำหนัก;projectไฟล์ | รอร้าน/profile |
| ปล่อยPRINT_READY | ผม | หลักฐานทุกgateครบและราคายืนยัน ไม่ต้องมีหุ่นเต็มก่อนพิมพ์ | ระบบแยกแล้ว ยังไม่ผ่าน |
| ASSEMBLED_CHECKED | ผู้ใช้ประกอบ/ตรวจ | เครื่องมือเข้าถึง แบตแน่น ฉนวน สายปลอดส่วนหมุน โรเตอร์คล่อง ฝาเปิดได้ ไม่มีเจาะเพิ่มไม่ระบุ;มวล/loadที่ชั่ง | แยกตรวจหลังผลิต |

หากพบราคาหรือมวลเกิน: เทียบแหล่งซื้อ/รวมผลิต/ลดวัสดุที่ไม่รับแรงและไม่ป้องกันก่อน ทวนCAD/mesh/simและtrialจุดที่กระทบ ห้ามลดผนังบานพับ1.6mm mounts/bearing battery retention หรือcutoff ห้ามใช้ballastเพิ่มมวลเพื่อให้rearloadผ่านโดยไม่ตรวจทั้งระบบ

ยังไม่ซื้อ ไม่พิมพ์ชิ้นใหญ่ ไม่แจ้งว่าPRINT_READYจนขนาดจริง/fit/profile/ราคา/น้ำหนักผ่าน รายงานนี้จะปรับตามหลักฐานที่ร้านส่งกลับ คำตอบรอในmeasurement_log.json,fit_log.json,quote_comparison.json

## หมวดงบที่ต้องรวม

- `drive_drivers`: 2บอร์ดต่อมอเตอร์ขนาน2ตัวต่อฝั่ง
- `sensors`: IMU Hall temperature magnets resistors
- `disconnect_fuse`: link/collar interface fuse holder
- `wiring_connectors`: power/signals connectors insulation ties straps foam (แยกpadIMUที่ชั่งต่อbody)
- `fasteners_inserts`: BOMสกรูทุกจุด รวมM8axle/nuts/washers/insert14/สำรอง
- `measurement_fit_service`: caliper/scale/photos/trial fit/insert5cycles
- `trial_prints`: round1+round2+support/finish/retrial
- `full_prints`: STL26ชิ้น/17แบบ support/inserts/finish
- `shipping`: ภาษีที่ยังไม่รวมและส่งทุกแหล่ง อย่านับซ้ำ
- `contingency`: เงินเผื่อ300ภายในเพดาน6000

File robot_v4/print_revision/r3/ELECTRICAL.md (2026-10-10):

# ตรวจไฟฟ้าก่อนล็อกชุดอะไหล่ / R3

สถานะ UNVERIFIED; ยังไม่ได้ทดสอบกระแสของมอเตอร์ หรือจ่ายไฟให้ชิ้นจริง แผนนี้ไม่พัฒนาเฟิร์มแวร์

แบตคง3S>=850mAh ตรวจที่3Sเต็ม12.6Vด้วย ไม่ใช้ค่าCโฆษณาแทนการตรวจ battery/XT30/wire/fuse/holder path กระแสรับได้จริง ผลต้องอยู่ `electrical/specs` แยกจาก `electrical/nominal` ซึ่งใช้จำลองร่างเท่านั้น

| รายการ | หลักฐานที่ต้องขอ / ตรวจ |
|---|---|
| มอเตอร์ขับ | รุ่นย่อย4ตัว, no-load/rated rpm/voltage, torque-current, start/stallแต่ละตัว; รวมคู่ที่ต่อขนานต่อบอร์ด |
| บอร์ดขับ | รุ่นPCBจริงและขนาดรวมterminal, Rlim/ค่าตั้งlimit, continuous currentที่PCB/อุณหภูมิจริง; ระบุวิธีจำกัดกระแสด้วยวงจรจริง |
| อาวุธ+ESC | KVตรงรุ่น, winding resistance/no-load current, spin-up/current-duration/profileที่ตรวจจริง, 3Sและรอบ/ESC ratingตรงSKU ไม่สมมติESCมีcurrent limiter |
| แบต+ตัดไฟ | 3S/ความจุ, voltage sag, battery/connector/wire/fuse/loop worst-case current path และขนาดพื้นที่บริการ |

เกณฑ์ซอฟต์แวร์ R3: limitบอร์ดไม่เกินพิกัดcontinuousที่ยืนยัน; กระแสเริ่มของคู่มอเตอร์ไม่เกินlimitที่ผ่านจริง; spin-upไม่เกินESC continuous; ผลรวมspin-up+2×drive limitไม่เกินpower path; บันทึกstart/stallและหลักฐานทั้งหมด เมื่อไม่ผ่านให้เปลี่ยนบอร์ดหรือระบบจำกัดกระแสแล้วทวนlayout/มวล/ต้นทุน ไม่กรอก3.6A peakเป็นcontinuous

MuJoCo R3อ่านKV/resistance/I0/voltage/drive-rpm/torqueจากspecsที่ยืนยัน มิฉะนั้นใช้nominalและระบุว่าunverified แรงขับจำกัดตามcurrent-limit/คู่stallเมื่อข้อมูลครบ แบบจำลองแรงบิดและแรงสัมผัสไม่ทำนายความร้อน/การเสียหาย และผลผ่านการเคลื่อนที่ไม่ได้ยืนยันกระแสจริง R3ใช้KV1300/R=.038Ω/I0=1.8Aจากคู่มือSURPASSC35V2 (R3-08) เก็บแหล่งต่อparameter; แบต3S850จากGaoneng และESC40Aจากร้านตรงSKU ค่าstart/stall/spin-upจริงและpower pathยังว่าง ไม่ใช้max50Aของมอเตอร์แทนกระแสที่วัดได้หรือถือเป็นcurrentlimiter

MDD3Aเป็นทางเลือกมีพิกัด3Acontinuous/ช่อง และ5Apeak<5sตามdatasheet;2บอร์ด/4ช่องช่วยแยกมอเตอร์แต่ไม่ปิดการจำกัดกระแสหรือstallโดยอัตโนมัติ rail5V200mAไม่ใช้เลี้ยงESP32วิทยุโดยไม่ตรวจ ไม่มีการเปลี่ยนแท่นDRVในCADร่างนี้

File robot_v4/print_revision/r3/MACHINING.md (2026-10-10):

# งานโลหะที่ประกบ R3 — หน่วยมม.

ไฟล์ใน `output_R3/DRAFT/metal` เป็นแบบต้นฉบับ revision เดียวกับ STL และ assembly STEP ยังรอขนาดอะไหล่จริง ไม่ใช้ไฟล์ V4 เดิมแทน brace บนหรือฐานมอเตอร์

| ชิ้น | จำนวน / วัสดุ | งานหลังตัด/กลึง |
|---|---|---|
| จาน beater | 2 / เหล็ก4140หรือHardox450 หนา6 | รูØ3.4×4 countersink90°ด้านนอก รูกลางØ14 รูลดน้ำหนักØ8×2; เจาะ/countersinkก่อนชุบแข็ง และถ่วงสมดุลร่วมดุม |
| Upright | ซ้าย1+ขวา1 / 6061-T6 หนา6 | รูแกนØ8.2; Ø2.5×4ต๊าปM3ทะลุ; ต๊าปM3ที่ขอบบน/ล่างเข้ารูbraceลึก8ตาม STEP; ซ้ายมี reliefมอเตอร์ด้านหลัง ใช้ไฟล์ซ้าย/ขวาแยก |
| Wedgelet | 2 mirror / เหล็กหนา2 | รูØ3.4×2 countersink90°ด้านบน ลับขอบหน้า ทำซ้าย/ขวาโดยอ้าง assembly |
| Brace บน | 1 / 6061 หนา3 | มีช่องหลบสายพานกลางใหม่; ใช้ DXF ของชิ้นบนโดยเฉพาะ |
| Brace ล่าง | 1 / 6061 หนา3 | รู4รูเหมือนแนวเดิม รูกลางใช้ nose skid หัวสกรูใต้ skidต้องเสมอผิว |
| แผ่นมอเตอร์อาวุธ | 1 / 6061 หนา3 | รูยึดตามมอเตอร์จริง + รูยึดPETGfeet2รู + reliefหลบมอเตอร์ขับหน้า; R3ใช้กากบาทคู่19/25mmจากSURPASSV2: dy±9.5,dz0 และdy0,dz±12.5; วัดยืนยันตัวจริง/ความลึกเกลียวก่อนผลิต |
| Skirt ข้าง/ท้าย | 2+1 / 5052หนา0.8 | รูØ2.2; ขยายเป็นร่องปรับสูงประมาณ1ตามแนวลาดก่อนประกอบ ลบคมทุกขอบ |

## ชิ้นกลึง

ส่ง STEP แยกชิ้นพร้อมรายละเอียดนี้ ไม่ตีความ STL เป็นแบบกลึง

- **Beater hub:** 6061 OD30 ยาว40 รูรับ608 nominalØ22ทะลุ ร่องสายพานกว้าง6 ลึก1.5 (รากØ27) ต๊าปM3×4ต่อปลาย วงPCD26 มุม45/135/225/315° ลึก8 ยืนยัน press fit กับลูกปืนจริงและร้านกลึงก่อนทำ ไม่กำหนดค่าพิกัดอัดจากค่าประมาณใน CADเพียงอย่างเดียว
- **Motor pulley R3:** 6061 OD30 ส่วนรอก x=−4…4 ยาว8 ร่องกว้าง6 ลึก1.5 รากØ27 เพิ่ม bossOD10ที่x=4…9ยาว5 รูกลางdraftØ4ตามคู่มือSURPASSV2 ไม่ใช้Ø5ของDYSเดิม; ค่าระยะสวมกลึงรอยืนยันเพลาจริง มีรูต๊าปM3รัศมีตาม STEPที่x=6เพื่อสกรูตัวหนอน ฝังแม่เหล็กØ3ลึก2ที่ด้านx=4สองรู ณระยะ7จากแกนตรงข้ามกัน ใช้แม่เหล็กกลับขั้วให้สมดุล รูต้องไม่ทะลุร่อง รอกกับดุมใช้รากØ27เท่ากันเพื่อ1:1
- **Spacers:** 6061 ID8.2/OD11 ยาว7สองตัว และ26หนึ่งตัว ลำดับระหว่างแผ่นตั้ง:7+608(7)+26+608(7)+7=54 ระหว่างหน้าด้านในแผ่นตั้ง; รวมแผ่นตั้ง6สองข้างเป็น66
- **แกนใบ:** สกรูM8เกรด12.9 ความยาวต้องรวม stack66+แหวน+เกลียวเต็มน็อตล็อก R3ใช้×80และจำลองหัว/แหวน/น็อตครบแล้ว มีช่องบล็อกขันØ21ในTPU ต้องยืนยันขนาดน็อตจริงก่อนล็อกการผลิต ไม่ใช้×70อัตโนมัติ
- **แกนบานพับ:** Ø3ยาว57 ร่องE-clipกว้าง0.6ถึงØ2.3 ณตำแหน่งปลายตามSTEP คู่กับDIN6799ขนาด2.3 ปลายด้านในเป็น stopกับแผ่นตั้ง

การประกอบเสร็จต้องยืนยัน: ลูกปืนไม่หมุนฟรีในดุม ชุดspacerล็อกวงในและโรเตอร์หมุนคล่อง โรเตอร์ไม่ถูแผ่นตั้ง และสกรูไม่ชนส่วนหมุน ก่อนปล่อยพิมพ์ตรวจ interface/สกรูใน `preflight.results` กับ trial; การประกอบเต็มบันทึก `assembly.results` หลังผลิต

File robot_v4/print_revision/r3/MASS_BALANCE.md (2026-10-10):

# มวลและสมดุล R3 — ยังเป็นค่าประมาณ

Build `319857d1a9f0a57815e203bf037db3a52d2c40b1a51fe7ead140aa4becb78534` ใช้SURPASSC3536V2 1300KV/109g และGNB8503S80A80g ตามcatalog ร่วมกับnominalที่ยังขาดและCADdensity ไม่ใช่น้ำหนักจริงหลังพิมพ์

| ตัวชี้วัด | R3 ร่างล่าสุด | เกณฑ์ / ส่วนเผื่อ |
|---|---:|---|
| มวลรวม | 1975.48g | เป้า1900:เกิน75.48g; hard2000:เผื่อ24.52g |
| โหลดล้อหลังเชิงสถิต | 10.484% | เป้า15:ขาด4.516จุดเปอร์เซ็นต์; min10:เผื่อ0.484จุดเปอร์เซ็นต์ |
| CG Y (+Yหน้า) | 8.7740mm | ที่มวล/axlesเดิม เป้า15%ต้องY<=4.8mm:ย้ายท้ายอีก3.9740mm |
| โมเมนต์ที่ต้องลดทางหน้า | 7850.6g·mm | ต้องรวมทุกชิ้นส่วน ไม่ใช้ย้ายแบตอย่างเดียว |
| แบตหลัก | 80g,Y−40.5mm | catalog63×30×24; rearedge−55.5พ้นrear drive |
| มวลชิ้นพิมพ์ประมาณ | 672.89g | ต้องแทนด้วยน้ำหนักslicerทุกSTLจำนวนครบ |

ร่างก่อนค้นเว็บSURPASSอยู่ที่1968.24g/10.646% ใช้มอเตอร์DYS102g; การใช้SURPASS109gเพิ่ม7gและรูปทรงฐาน/ฝาใหม่เปลี่ยนมวลอีกเล็กน้อย จึงทำให้เผื่อน้ำหนักและสมดุลลดลง ข้อมูลจริงที่พบไม่ได้ทำให้เป้าหมายผ่านเอง

เมื่อเทียบR2 (1969.91g/10.568%): แบตY−38→−40.5ลดโมเมนต์200g·mmเท่านั้น การเปลี่ยนมอเตอร์ด้านหน้าและแผ่นฐานต้องรวมผลด้วย ไม่เลื่อนแบตทะลุมอเตอร์ท้ายหรือเติมballastเพื่อให้ตัวเลขผ่าน

ลำดับปรับ: ล็อกdrive/driver/powerpathที่เข้ากัน→วัดมวลอะไหล่และโลหะ→ใส่น้ำหนักslicerทุกชิ้น→จัดbattery/electronics/wiringไปท้ายเฉพาะที่ไม่ชนและซ่อมได้→ลดวัสดุที่ไม่รับแรงและไม่มีหน้าที่ป้องกันพร้อมตรวจCAD/mesh/simใหม่ ห้ามลดmount/bearing/hinge1.6mm/batteryretention/cutoff/armorที่ป้องกัน

PRINT_READYต้องผ่านhard2000g/10%และงบ6000 รวมเผื่อ300ก่อน หากยังพลาดเป้า1900g/15%ต้องให้ผู้ใช้ตัดสินใจจากslicer+ชั่งจริงและbuildล่าสุด บันทึกtarget_decisionพร้อมหลักฐาน; ยังไม่มีการยอมรับข้อยกเว้นนี้

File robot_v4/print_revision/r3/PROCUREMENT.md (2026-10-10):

# รายการจัดหาและงบบางส่วน — V4_PRINT_R3

รวบรวมวันที่ 2026-10-10; ราคาที่ไม่ได้ตรวจใหม่อ้างอิงวันที่ 2026-10-08 (TH03/R3-07/R3-09 checked2026-10-10); ผู้ใช้ยังไม่ได้ซื้ออะไหล่ ไม่มีคำสั่งซื้อหรือใบเสนอราคาที่ร้านยืนยัน

**ยอดราคาที่พบ 3,223 บาท; เพดานที่เหลือ 2,477 บาทหลังกันเงินเผื่อ 300 บาท** ยอดนี้ยังไม่ใช่ราคาทั้งโครงการ รายการรอราคาไม่ถูกนับเป็นศูนย์ และไม่ถือว่างบผ่าน

| รายการ | จำนวนใช้ / หน่วยขาย | ยอดเว็บ (บาท) | แหล่ง / สิ่งต้องยืนยัน |
|---|---:|---:|---|
| มอเตอร์ขับ DCM068 | 4 / 1 ต่อหน่วยขาย | 760 | [TH01](https://www.fromfactory.net/product/6096/ดีซีมอเตอร์-พร้อมเกียร์ทด-jga25-370-gear-dc-motor-12v-high-torque-5-10-30-60-400-rpm-ขนาด-25mm); 190บาทเป็นราคาเว็บ; stockขัดแย้งระหว่างเว็บร้านเดียวกัน ต้องยืนยันครบ4 |
| SURPASS C3536 V2 1300KV SKU02373 | 1 / 1 ต่อหน่วยขาย | 840 | [R3-07](http://www.udshobby.com/p/2372?pid=2373); ราคาvariant840ตรวจ10ต.ค.; CADและรอกØ4ปรับตามคู่มือแล้ว ยังต้องตรวจESC/currentและมิติที่ไม่ระบุ |
| Skywalker40A V2 PN80060140 | 1 / 1 ต่อหน่วยขาย | 490 | [TH03](https://www.abcflying.com/product/8569/hobbywing-skywalker-40a-v2-ubec-3s-4s); 490/instock=1ตรวจ10ต.ค.; ESC40Aยังไม่รับรองคู่SURPASSmax50A |
| GNB8503S80A 3S85080C XT30 | 1 / 1 ต่อหน่วยขาย | 605 | [R3-09](https://www.fpvonly.com/product/ส่งฟรี-gnb-3s-300mah-6500mah-gaoneng-แบต-lipo-battery-xt30-xt60-hv-แบตเตอรี่-แบต-อุปกรณ์-rc-รถบังคับ/11000371400004074/4101); FPVONLY3-20/SKU04101ราคา605ตรวจ10ต.ค.; exactvariantInStock ไม่ใช่HV120C |
| ESP32 30pin Type-C CH340C | 1 / 1 ต่อหน่วยขาย | 180 | [TH04](https://www.mikroelec.com/product/2990/esp32-30pin-type-c-ch340c-esp-wroom-32-board); ผู้ใช้ยังไม่มีบอร์ด; รอความสูงหลังต่อสาย |
| DRV8871 ModuleMore SKU01477 | 2 / 1 ต่อหน่วยขาย | 150 | [TH05](https://www.modulemore.com/product/1477/บอร์ดขับมอเตอร์-drv8871-3-6a-motor-driver-dc-h-bridge-pwm-driver-module); 2บอร์ด; ต้องตรวจcurrent-limitกับ2มอเตอร์ต่อช่อง |
| GY-521 MPU6050 | 1 / 1 ต่อหน่วยขาย | 80 | [TH06](https://www.cybertice.com/product/40/gy-521-mpu6050-6-axis-imu-module-โมดูลวัดความเร่งและไจโรสโคป-3-แกน); รอความสูง/ขาต่อและมวล |
| A3144 IC | 1 / 1 ต่อหน่วยขาย | 10 | [TH10](https://www.allnewstep.com/product/351/a3144-a3144e-oh3144e-hall-effect-sensor); IC ไม่ใช่module; รวมขา/ฉนวนด้วย |
| DS18B20 TO92 | 2 / 1 ต่อหน่วยขาย | 50 | [TH11](https://www.arduitronics.com/product/383/ds18b20-temperature-sensor); 2ตัวตามแบบ |
| M3x4x5 inserts (10pcs/ถุง) | 14 / 10 ต่อหน่วยขาย | 40 | [TH09](https://www.friendrobotshop.com/product/385/m3x4x5-insert-nut-สำหรับงานพิมพ์-3d-สำหรับน๊อต-m3-สูง-4-มม-ขนาดเส้นผ่านศูนย์กลาง-5-มม-10-ชิ้น); ต้องซื้อ2ถุง รวม40บาท; trialfitยังไม่ผ่าน |
| SRT608ZZ 8x22x7 | 2 / 1 ต่อหน่วยขาย | 18 | [TH08](https://sunrise.co.th/en/product/deep-groove-ball-bearings-8x22x7-abec-1-jis-b1514-class-0); 2ตลับ; รอmass/stock |
| จอยBluetooth | 1 / 1 ต่อหน่วยขาย | รอราคา | รอรุ่น/ราคา; รอmodelที่จับคู่Bluepad32ได้จริง ไม่ถือว่าcloneทุกรุ่นใช้ได้ |
| เครื่องชาร์จ+แหล่งจ่าย+สายแปลง | 1 / 1 ต่อหน่วยขาย | รอราคา | รอรุ่น/ราคา; รอรุ่นที่balance-charge3Sพร้อมอุปกรณ์ครบ |
| ตัวตัดไฟ+ฟิวส์+holder | 1 / 1 ต่อหน่วยขาย | รอราคา | รอรุ่น/ราคา; รอขนาด/พิกัดกระแสจริง |
| สายไฟ+XT30+สายสัญญาณ+R | 1 / 1 ต่อหน่วยขาย | รอราคา | รอรุ่น/ราคา; รวม3คู่XT30และฉนวน; TH18ยังไม่แยกvariant |
| แม่เหล็ก3x2mmสองลูก | 1 / 1 ต่อหน่วยขาย | รอราคา | รอรุ่น/ราคา; TH12รอราคาตัวเลือก |
| สายรัดแบตสองเส้น+ties | 1 / 1 ต่อหน่วยขาย | รอราคา | รอรุ่น/ราคา; ต้องผ่านslot10mmและรอบแบตจริง |
| สายพานกลมPU5mmเชื่อมวง | 1 / 1 ต่อหน่วยขาย | รอราคา | รอรุ่น/ราคา; รอราคาความยาวขั้นต่ำ/เชื่อม/ทดลอง |
| สกรู/น็อต/แหวน/สำรองยกเว้นinsert | 1 / 1 ต่อหน่วยขาย | รอราคา | รอรุ่น/ราคา; ตามASSEMBLY.md ไม่รวมinsertซ้ำ |
| M8x80hex12.9+น็อตล็อก+แหวน | 1 / 1 ต่อหน่วยขาย | รอราคา | รอรุ่น/ราคา; TH14รอแบ่งขายและเกลียวตรงแบบ |
| แกนบานพับ3x57สองแกน+Eclips | 1 / 1 ต่อหน่วยขาย | รอราคา | รอรุ่น/ราคา; ร่องตามSTEP รอร้านกลึงเสนอราคา |
| UHMW3mm skid | 1 / 1 ต่อหน่วยขาย | รอราคา | รอรุ่น/ราคา; ตัด/countersinkตามMACHINING |
| แผ่นโลหะตัด9แบบ | 1 / 1 ต่อหน่วยขาย | รอราคา | รอรุ่น/ราคา; แยกวัสดุ/จำนวนตามmanifestและMACHINING |
| งานกลึงรอก/ดุม/spacers/ต๊าป/เก็บคม | 1 / 1 ต่อหน่วยขาย | รอราคา | รอรุ่น/ราคา; รวมcountersink/ร่อง/งานประกอบที่ระบุ |
| พิมพ์ชิ้นทดลอง+เก็บงาน | 1 / 1 ต่อหน่วยขาย | รอราคา | รอรุ่น/ราคา; 2รอบ couponทีละ0.1mmแล้วสร้างใหม่พิมพ์ชุดสวมเต็ม; ไม่จำเป็นต้องพิมพ์ทุกcoupon |
| พิมพ์TPU95A/PETGชุดเต็ม+support/เก็บงาน | 1 / 1 ต่อหน่วยขาย | รอราคา | รอรุ่น/ราคา; 26ชิ้น17แบบตามmanifest; ชิ้นใหญ่ยังไม่อนุมัติ |
| ค่าส่ง/ภาษีที่ยังไม่รวม | 1 / 1 ต่อหน่วยขาย | รอราคา | รอรุ่น/ราคา; อย่านับซ้ำส่วนที่รวมในใบเสนอราคา |
| บริการวัด ชั่ง ทดลองสวม ฝัง insert | 1 / 1 ต่อหน่วยขาย | รอราคา | รอรุ่น/ราคา; แยกจากค่าพิมพ์ทั้งสองรอบ; ขอราคาและหลักฐาน |

## ลำดับปิดข้อมูล

1. ตรวจข้อมูลที่ยังขาดของมอเตอร์ขับครบ 4 ตัว มอเตอร์อาวุธ แบต และบอร์ดขับก่อนซื้อ; R3 อ่าน WEB_CONFIRMED.md สำหรับข้อมูลเว็บที่ปิดแล้ว และใช้ SUPPLIER_REQUESTS.md เฉพาะส่วนที่เว็บไม่ระบุ
2. ขอราคางานกลึง/ตัดโลหะ ชิ้นทดลอง และชุดพิมพ์เต็มจากไฟล์ DRAFT revision เดียวกันก่อนสั่งงาน รวม support เก็บงาน ภาษีและส่ง
3. ล็อก SKU และรับของมาวัด กรอก actual/evidence ใน inputs_R3.json แล้วสร้าง revision ใหม่; ค่าจากเว็บไม่ใช่ actual
4. พิมพ์เฉพาะชิ้นทดลองที่ได้รับอนุมัติและใช้ profile เดียวกับชุดเต็ม บันทึกผลตาม FIT_TEST.md; หาก layout เปลี่ยนใช้ชุดทดลองจาก build ใหม่
5. ปิด slicer/มวล/โหลดล้อหลัง/ราคาและผลตรวจประกอบล่วงหน้าทุกข้อ; ประกอบจริงตรวจแยกหลังผลิตก่อนปล่อยชุดใหญ่

ราคาสกรูใช้ BOM ใน ASSEMBLY.md และต้องรวมแหวน น็อตล็อก น็อตฝัง สำรอง และ insert 14 จุด (ซื้อ 2 ถุง ถุงละ 10 ตัว)
R3เลือก SURPASS C3536 V2 1300KV SKU02373 เป็นผู้สมัครหลัก ใช้ราคา840ตรงvariant และแก้รอกØ4/รูฐาน/มวล/โมเดลตามคู่มือ; ESC40Aยังต้องตรวจคู่มอเตอร์ที่ระบุmax50A
มวล/สมดุลล่าสุดอ่าน output_R3/STATUS.md; ต้องถึงเป้า1900g/15% หรือมีการตัดสินใจจากส่วนเผื่อ โดยขั้นต่ำ2000g/10%ยังบังคับและต้องใช้slicer+มวลจริง
จอยและเครื่องชาร์จเป็นต้นทุนโครงการ แม้ไม่อยู่บนตัวหุ่น ไม่สมมติว่าเป็นของที่มีแล้ว

สร้างรายงานซ้ำ: `.venv-v4-print/bin/python robot_v4/print_revision/procurement.py --catalog robot_v4/print_revision/r3` จาก root ของ repository

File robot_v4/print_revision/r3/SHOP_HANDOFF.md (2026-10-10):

# ใบส่งงานร้านพิมพ์ — Robot V4 Print R3

**ขอราคาและพิมพ์ชิ้นทดลองก่อน ไม่ใช่ใบอนุมัติผลิตชุดใหญ่** ห้ามเปลี่ยนวัสดุ สเกล รูประกอบ หรือซ่อม mesh โดยไม่ส่งรายละเอียดกลับให้แก้ต้นฉบับ

## ข้อมูลที่ร้านต้องระบุ

| รายการ | คำตอบร้าน |
|---|---|
| ชื่อร้าน / ผู้รับงาน | รอยืนยัน |
| เครื่อง / พื้นที่พิมพ์ใช้ได้จริง XYZ | รอยืนยัน |
| หัวฉีด / ความกว้างเส้น / layer height | รอยืนยัน |
| Slicer / version / profile | รอยืนยัน |
| TPU 95A ยี่ห้อ/รุ่น และ PETG ยี่ห้อ/รุ่น | รอยืนยัน |
| Brim / support / วิธีเก็บงาน | รอยืนยัน |
| ราคาทดลอง รวมเก็บงาน/ส่ง | รอยืนยัน |
| ราคาชุดเต็ม รวมเก็บงาน/ส่ง | รอยืนยัน |
| น้ำหนักและเวลาพิมพ์แยกตาม STL | รอยืนยัน |

ถาดปัจจุบันประมาณ **190.5 × 217.3 × 54 มม.** ก่อน brim ฐานใช้ได้จริง 220 × 220 มม. ไม่พอสำหรับ brim 5 มม. โดยวางตรงตามแกน ให้เลือกเครื่องที่รองรับชิ้นเดียวรวม brim ที่ตกลง ห้ามตัดแบ่งตัวถังเพื่อแก้เรื่องฐานพิมพ์

## การตั้งค่าตั้งต้นสำหรับลองสไลซ์

ใช้หัวฉีด 0.4 มม. และ layer 0.2 มม. เป็นค่าประเมินเริ่มต้น ร้านต้องยืนยัน profile ตามวัสดุจริง

| กลุ่ม | วัสดุ | ตั้งต้น | ท่าที่ส่งออก / สิ่งต้องตรวจ |
|---|---|---|---|
| ถาดและฝา | TPU 95A | 4 walls, 60% gyroid | พื้นลงฐาน; ฝามีหลังคาโค้งและช่องสายพาน ต้องตรวจ support ถอดได้ |
| ยางล้อ | TPU 95A | 4 walls, เริ่มประเมิน 60% gyroid | หน้าวงแหวนลงฐาน ตรวจความยืดหยุ่นและ fit กับดุม |
| บานพับ/ดุม | PETG | 4 walls, ≥80% infill | รูแกนบล็อกเป็นแนวนอน; carrier/ดุมวางแกนหลักแนวตั้ง |
| ถาดแบต/แท่น/เสา/ฐานมอเตอร์ | PETG | 4 walls, เริ่ม 80% infill | ตรวจ slot สายรัด รูสกรู และช่องน็อต ไม่มีการลดเนื้อรอบรูบานพับต่ำกว่า 1.6 มม. |
| เสา Hall / collar | PETG | 4 walls, เริ่ม 80% infill | เสา Hall วางนอนใน STL ตรวจ support ที่ยื่นออก |

ชุดขนาด รู และจำนวนใช้ `output_R3/manifest.json` ของ build ล่าสุด อย่าใช้คู่มือ V4 เดิมแทนรายการนี้ ไม่มีชิ้น mirror ให้ร้านสร้างเองแล้ว

## ผลที่ต้องส่งกลับ

- ไฟล์โครงการ slicer จริง เก็บ printer/material profile ท่าวางชิ้น support และจำนวนให้ครบ
- ภาพ layer preview ของบานพับ รู insert ช่องน็อตดุม ฝาหลังคาโค้ง และแนวสายพาน
- ตารางน้ำหนักและเวลาต่อ **หนึ่งชิ้นของแต่ละ STL** โปรแกรมคูณจำนวนเอง รวมข้อมูล support แยกออกจากมวลชิ้นที่จะอยู่บนรถ
- ใบเสนอราคาแยกชิ้นทดลอง/ชุดเต็ม วัสดุ งานเก็บผิว และส่ง ไม่ถือว่างบพิมพ์เส้นเดิม 550 บาทเป็นราคาจ้างร้าน
- ผลการทดลองตาม `FIT_TEST.md` และ SHA256 build ที่ใช้อยู่ หากเปลี่ยน profile/วัสดุ/ท่าพิมพ์ในจุดสวม ต้องลองจุดนั้นใหม่

เงื่อนไขงบ: รวมอะไหล่ โลหะ ชิ้นพิมพ์ทดลอง ชุดเต็ม และค่าส่งทั้งโครงการไม่เกิน **6,000 บาท** หากเกิน ให้รายงานก่อนผลิต ไม่มีคำสั่งซื้อหรือการอนุมัติสั่งผลิตในใบนี้

R3 ใช้สองรอบ: coupon→รับค่าที่เลือก→ผมสร้างแบบใหม่→ทดลองดุมยาง/hinge/carrier/ฝาเต็ม เงื่อนไขคือเพลาครบ4และฝาขันคลาย5รอบ บันทึกround1/round2 SHAและprofileจริงในfit_log.json ร้านต้องยืนยันบริการวัด/ชั่งด้วยคาลิปเปอร์และหลักฐานภาพด้วย ใช้profile_evidenceเก็บsettingทั้งTPU/PETGและท่าที่เกี่ยวกับรูให้ครบ

ก่อนPRINT_READYต้องรวมราคาเกมแพด เครื่องชาร์จ งานวัด สวม trialสองรอบ ภาษีและส่งทุกหมวด กับเงินเผื่อ300 ไม่มีรายการไม่ทราบนับเป็น0 ขอร้านระบุว่าราคาพิมพ์เต็มใช้ได้หลังเปลี่ยนค่ารูจากtrialหรือไม่

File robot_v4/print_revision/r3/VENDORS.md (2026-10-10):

# ร้านสำหรับขอราคา R3

คัดจากหน้าเว็บของผู้ให้บริการ 10 ต.ค. 2026; ยังไม่ได้ติดต่อร้านหรือรับใบเสนอราคา ค่าใช้จ่ายที่ขาดเป็น null ทุกช่อง ไม่ถือว่าร้านรับงานนี้แล้ว

| ID / ร้าน | สิ่งที่เว็บระบุ | ต้องให้ร้านยืนยัน | ติดต่อ |
|---|---|---|---|
| P1 [TKK3D](https://tkk3dprinting.com/fdm-3dprinting/) | FDM TPU/PETG; support removal/finish; fit review/trial fit described; parcel shipping | TPU95A brand; usable bed + brim; caliper/mass service; two-round trial/insert5cycles; saved profile and slicer project | LINE @tkk3d; sale@tkk3dprinting.com;092-599-5661 |
| P2 [Threelines 3D](https://3dprint.threelines.online/) | TPU/PETG; STL/OBJ/STEP/3MF; one piece; nationwide shipping | TPU95A brand; usable bed + brim; measure/fit service; inserts/finish; saved profile/project | 097-969-8670; website contact |
| M1 [MALIEV](https://www.maliev.com/services/cnc-machining) | CNC milling/turning; prototype single parts; nationwide service | 6061 and steel grades per BOM; plate cutting subcontract; tolerances/threads/finish; hinge pin grooves; VAT/shipping | website request a quote |
| M2 [SST Intertech โรงกลึงท่าข้าม](https://www.sstintertech.com/) | CNC turning/milling; single-part prototype; laser/fixtures | exact metal grades; fits/threads/finish; nationwide parcel shipping; VAT/minimum cost | website contact |

เสนอ TKK3D เป็นร้านเริ่มขอราคาเพราะหน้าเว็บระบุทดลองสวมก่อนส่ง แต่ยังต้องให้ยืนยันบริการวัดด้วยคาลิปเปอร์และ TPU95A; ไม่มีการรับรองจากเราแทนร้าน

[3D Print @ Nakhonpathom](https://3dprintnakhonpathom.com/) ระบุหน้าเว็บล่าสุดว่ารับ PETG และยังไม่รับวัสดุอื่น จึงไม่นับเป็นหนึ่งในสองร้าน TPU สำหรับชุดเต็ม

ไฟล์ข้อความพร้อมส่งอยู่ RFQ/P1_TKK3D.md, P2_Threelines.md, M1_MALIEV.md, M2_SST.md เปรียบเทียบคำตอบใน quote_comparison.json และงบทุกหมวดใน inputs_R3.json/cost ไม่มี quote จริงจึงยังล็อกร้านหรืออนุมัติผลิตไม่ได้

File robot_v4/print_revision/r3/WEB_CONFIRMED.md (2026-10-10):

# ข้อมูลเว็บที่ยืนยันเพิ่มและนำเข้า R3 — 10 ต.ค. 2026

ตรวจหน้าสินค้าของร้านตรงรุ่นและเอกสารผู้ผลิตเอง ข้อมูลด้านล่างเป็น **ข้อมูลที่เผยแพร่** ใช้แก้ CAD ร่างและเปรียบเทียบอะไหล่ได้ ไม่ใช่ค่าที่ชั่ง/วัดชิ้นที่จะได้รับ ผลทดลองสวม หรือใบเสนอราคาผลิต ทุกช่อง `actual` และสถานะ physical verified คงเดิม

## สิ่งที่ปิดจากเว็บได้แล้ว

| รายการ | หลักฐานตรงรุ่น | ผลที่ยืนยันได้ / นำไปใช้ |
|---|---|---|
| มอเตอร์อาวุธ | [UDSHOBBY รุ่นย่อย1300KV SKU02373](http://www.udshobby.com/p/2372?pid=2373) + [คู่มือ SURPASS C35 V2](https://myosuploads3.banggood.com/products/20230705/20230705015052C35V2Manual.pdf) | ราคา840บาท, variant instock=1; C3536-V2 SP-235360-01, Ø35×34.5mm,109g,เพลาØ4ยื่น20mm,รู4M3ระยะ19/25mm,1300KV,R=.038Ω,I0=1.8A,max50A/680W,7–15V |
| แบตหลัก | [FPVONLY3-20 SKU04101](https://www.fpvonly.com/product/ส่งฟรี-gnb-3s-300mah-6500mah-gaoneng-แบต-lipo-battery-xt30-xt60-hv-แบตเตอรี่-แบต-อุปกรณ์-rc-รถบังคับ/11000371400004074/4101) + [Gaoneng GNB8503S80A](https://www.gaoneng.shop/products/gaoneng-gnb-3s-11.1v-850mah-80c-xt30-lipo-battery) | ราคา605บาท, exactvariant InStock;3S850mAh80C,XT30,63×30×24mm,80±3g; ใช้ถาดแบตในR3แล้ว ไม่ใช้ราคาหรือขนาดของHV120C/DOGCOMแทน |
| ESC | [ABCFlying Skywalker40AV2](https://www.abcflying.com/product/8569/hobbywing-skywalker-40a-v2-ubec-3s-4s) | ตรวจราคา490และinstock=1ใหม่; พิกัด40Aยังไม่รับรองการเร่งอาวุธคู่กับSURPASSที่ระบุmax50A |
| มอเตอร์ขับทางเลือก | [ORTECH JB361 SKU00378](https://www.ortech-online.com/product/378) | ราคา130บาท/ตัว,12V400rpm,instock=1; มีภาพมิติØ25,ตัว~50,เพลาØ4ยื่น11.5–12mm,flatdepth.5mm,บ่าØ7ยื่น2.5mm,2M3ระยะ17mm; **ไม่ผ่านการแทนตรงแบบปัจจุบัน** ซึ่งต้องเพลายื่น>=16mm |
| บอร์ดขับทางเลือก | [Cytron Thailand MDD3A](https://th.cytron.io/cytron/p-3amp-4v-16v-dc-motor-driver-2-channels) + [datasheetที่ผู้ผลิตเชื่อม](https://docs.google.com/document/d/1ax3gSo0srTzoSr2bo8ETLym0OqrYjlk_JCZK4kxtfXg/edit) | หน้าเว็บ320บาทรวมVAT;2ช่อง,4–16V,3Aต่อเนื่อง/ช่อง,5Apeak<5s;PCB48.26×41.66mm,รูØ3สี่รูระยะ43.18×36.58mm; ถ้าแยกหนึ่งช่องต่อมอเตอร์ใช้2บอร์ด640บาท ยังไม่เปลี่ยนCADเพราะขาดมวล/ความสูง/currentlimitและกระแสstallของมอเตอร์ |
| มอเตอร์อาวุธสำรอง | [DYS D3536 standard](https://www.dys.hk/product/D3536.html) | D3536-06 order281406,1250KV,Ø35×36mm,102g,R=.034Ω,เพลาØ5ความยาวรวม53.5mm; **53.5ไม่ใช่ความยาวเพลาที่ยื่น** ยังไม่พบstockไทยตรงรุ่นที่ยืนยันได้ |

## แบบ R3 ที่แก้จากหลักฐานนี้

- เลือก SURPASS1300KV เป็นผู้สมัครหลักแทน DYS1250KV; DYSเป็นสำรอง ยังไม่มีการสั่งซื้อและยังไม่ยืนยันความเข้ากันได้ทั้งระบบ
- รอกอาวุธ boreØ5→Ø4; รูแผ่นฐานจากกากบาท16/19→19/25mm; ตัวมอเตอร์ยาว36→34.5mm และมวล102→109g
- รู4M3เป็นสองคู่ตรงข้ามระยะ19และ25mm หมุนมอเตอร์ให้คู่19อยู่แกนYและคู่25อยู่แกนZ ไม่ตีความเป็นรูสี่มุมสี่เหลี่ยม19×25
- เพิ่มส่วนเพลายื่นใน CAD ร่าง ตรวจการสวมรอก13mmและตำแหน่งสกรูตัวหนอนที่x=6; MuJoCoใช้1300KV/.038Ω/1.8Aตามคู่มือและหลังคาฝาตามความยาวมอเตอร์ใหม่
- Øบ่ามอเตอร์อาวุธและความลึกเกลียวยังไม่มีมิติในคู่มือ จึงคง nominal เฉพาะช่องนั้นพร้อมสถานะไม่ยืนยัน ไม่เติมเป็นค่าผู้ผลิต
- JB361มีแบบขนาดแล้ว แต่เพลาสั้นกว่าข้อกำหนดปัจจุบัน; ต้องออกแบบดุม/ผนัง/ระยะสกรูใหม่ก่อนพิจารณาเลือก ไม่ส่ง drawing รุ่นอื่นมาแทน DCM068

มวลและผลจำลองล่าสุดอ่าน [MASS_BALANCE.md](MASS_BALANCE.md) และ [VERIFICATION.md](output_R3/VERIFICATION.md) ยังเป็นผลประมาณจาก catalog/nominal/CADdensity

## การอ่านสถานะสต็อกและข้อขัดแย้ง

`InStock`/`instock=1` หมายถึงหน้าเว็บแสดงพร้อมขาย ไม่ยืนยันจำนวน4ตัวหรือการจองสินค้า ร้านORTECHไม่เผยแพร่จำนวน; ไม่บวกstockของเว็บร้านเดียวกัน หน้าCytronที่เครื่องมือเว็บอ่านแสดง38แต่cacheระบุ4สัปดาห์ และการอ่านสดติดหน้าchallenge จึงไม่ถือ38เป็นจำนวนที่ยืนยันวันนี้

ร้านUDSHOBBYใช้ parentSKU02372 แต่รุ่น1300คือSKU02373และ1500คือ02374 ต้องเลือกรุ่นย่อย; ข้อความร้านมีตัวเลขno-load currentผิด/สลับ จึงใช้แถว1300KVในคู่มือผู้ผลิต1.8Aแทน แบตเลือก3-20 8503S80A/SKU04101 ไม่ใช่3-21HV120C/SKU05487 แม้ความจุ850เท่ากัน

ORTECHลงweight100gในข้อมูลขาย แต่ไม่ระบุว่าชั่งมอเตอร์หรือพัสดุ จึงไม่ใช้เป็นมวลติดตั้ง ภาพของSKUเดียวกันระบุเพลา~12mm/บ่า~2mm ขณะที่drawing11.5/2.5mm จึงบันทึกความคลาดเคลื่อนและยังต้องวัดจริง ไม่เพิ่มความเที่ยงตรงจากภาพถ่ายเอง

หลักฐานที่เก็บ: [ข้อมูลรุ่นย่อยจากหน้าเว็บ](evidence/web_variants_20261010.json), [คู่มือSURPASS](evidence/SURPASS_C35_V2_manual.pdf), [แบบJB361](evidence/ORTECH_JB361_dimensions.jpg), [datasheetMDD3A](evidence/Cytron_MDD3A_datasheet.pdf), [แหล่งและค่าที่เผยแพร่](sources.json) และ [สรุปข้อมูลใหม่](web_confirmed.json) เก็บinputsก่อนแก้ในhistory; R1/R2เดิมคงไว้

## งานที่ยังต้องปิด

ค้น exactmotorขับที่เพลายื่นพอ พร้อมกราฟtorque/current/massและจำนวน4ตัว หรือออกแบบใหม่สำหรับJB361แล้วตรวจทั้งระบบ; ตรวจboard current limit/thermal; เลือกpowerpathและESCให้รองรับกระแสรวม; ปิดจอย/charger/BOMย่อยและราคาผลิตครบหมวด เว็บใช้ยืนยันรายละเอียดสินค้าและเตรียมแบบได้ ส่วนสวมจริง การตั้งเครื่องร้าน น้ำหนักจากslicerและใบเสนอราคาเฉพาะงานต้องมีหลักฐานจากงานนั้น

งบบางส่วนขณะนี้3,223บาท + เผื่อ300บาท เหลือ2,477บาทสำหรับ17หมวดที่ยังไม่ทราบราคา จึงยังไม่ถือผ่าน6,000บาท ไม่ใช้รายการไม่มีราคาเป็นศูนย์

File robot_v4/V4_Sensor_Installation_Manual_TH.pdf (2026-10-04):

## ENGINEERING MANUAL · V4-SNS-MAN-001 · REV A

# คู่มือการติดตั้ง Sensor Robot V4 — Vertical Beater

ตำ แหน่ง มุม ขายึด การเดินสาย การต่อเข้า ESP32 การ Calibrate การทดสอบ และ Checklist ก่อนใช้

## งานจริง

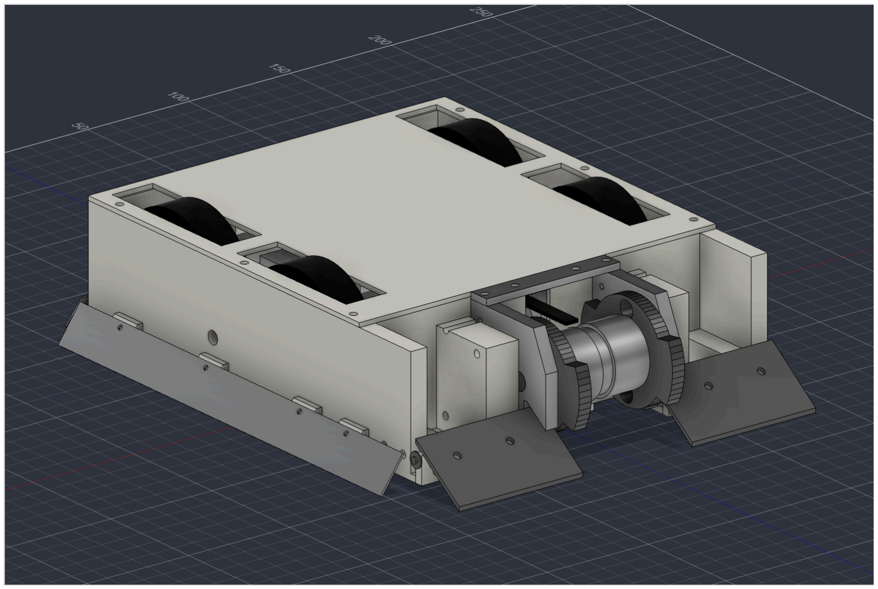
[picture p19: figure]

แบบอ้างอิง | robot_v4/ROBOT_V4_Beater.f3d / .step สร้างจาก build_robot_v4.py — git commit 9321d02 (branch v4-vertical-beater, 4 ต.ค. 2026)
เฟิร์มแวร์อ้างอิง | robot_v4/firmware/v4_controller/v4_controller.ino (commit เดียวกัน)
Sensor ในคู่มือ | S1 IMU GY-521 · S2 Hall A3144 + แม่เหล็ก · S3 DS18B20 (ESC อาวุธ) · S4 DS18B20 (มอเตอร์ขับหน้า ซ้าย) · S5 ตัวแบ่งแรงดันแบต
สถานะแบบ | ยังไม่ผ่านเกณฑ์ผลิต · เฟิร์มแวร์ยังไม่ได้ compile · ESC/ESP32/DRV8871/แบต ในแบบเป็นกล่องแทนขนาด (envelope) ยังไม่มีที่ยึด
วันที่ออกเอกสาร | 4 ตุลาคม 2026
ผู้ติดตั้ง | ผู้ตรวจ | วันที่ติดตั้ง

V4-SNS-MAN-001

Robot V4 — คู่มือการติดตั้ง Sensor · Rev A (CAD 9321d02) | หน้า 2 / 41

# สารบัญ

1 | วิเคราะห์ Robot V4 | 4
1.1 | โครงสร้างตัวรถ | 4
1.2 | ระบบพิกัดของคู่มือ (Robot V4 Coordinate System) | 5
1.3 | ผิวอ้างอิงสำ หรับวัดจริง | 7
2 | Sensor Layout Overview | 8
3 | รายละเอียด Sensor แต่ละตัว | 10
3.1 | Sensor S1 — IMU (Upside-down + Yaw rate) | 10
3.2 | Sensor S2 — Weapon RPM Hall Sensor | 11
3.3 | Sensor S3 — ESC Temperature (DS18B20) | 13
3.4 | Sensor S4 — Drive Motor Temperature (DS18B20) | 14
3.5 | Sensor S5 — Battery Voltage Divider | 15
4 | เหตุผลในการเลือกตำ แหน่ง | 17
4.1 | เทียบกับเกณฑ์ทั่วไปของหุ่นยนต์เคลื่อนที่ | 17
5 | Sensor Coverage Map (ฉบับ V4) | 18
6 | Mechanical Installation | 20
6.1 | ขายึดพิมพ์ 3D ของ S2 (Hall Post) | 20
6.2 | การใส่แม่เหล็ก S2 และตรวจขั้ว | 21
7 | Wiring | 22
7.1 | สายและขั้วต่อ | 24
8 | Cable Routing | 25
8.1 | กฎป้องกัน Noise | 26
9 | Installation Procedure | 27
10 | Calibration | 31
10.1 S1 IMU | 31
10.2 S2 Hall (เทียบกับเครื่องวัดรอบ) | 31
10.3 S3/S4 DS18B20 | 32
10.4 S5 แรงดันแบต | 32
11 | Sensor Test | 33
12 | Blind Spot Test (ทดสอบตรวจกลับหัวทุกมุม) | 34
13 | Collision Safety | 36
14 | Installation Checklist | 38
15 | Maintenance | 39
15.1 การทำ ความสะอาด | 39
16 | Troubleshooting | 40
A | ภาคผนวก A — แบบบันทึกค่าที่วัดจาก Robot V4 จริง | 41
B | ภาคผนวก B — แหล่งข้อมูลและขอบเขต | 41

Robot V4 — คู่มือการติดตั้ง Sensor · Rev A (CAD 9321d02) | หน้า 3 / 41

วิธีใช้คู่มือนี้

หน่วยทั้งหมดเป็น มิลลิเมตร (mm) และองศา (°) เว้นแต่ระบุไว้ ทุกตัวเลขมีป้ายบอกที่มา เพื่อให้ช่างรู้ว่าค่าไหนเชื่อได้ทันที และค่าไหนต้อง วัดเอง
Table 0.1 ป้ายที่มาของค่า
ป้าย | ความหมาย
CAD | ค่าจาก build_robot_v4.py / ROBOT_V4_Beater.f3d
FW | ค่าจากเฟิร์มแวร์ v4_controller.ino
STATUS | ค่าจาก robot_v4/STATUS.md หรือ manufacturing/README.md
แนะนำ | ข้อแนะนำ ของคู่มือนี้ ยังไม่อยู่ในแบบ CAD
วัดจริง | ต้องวัดจาก Robot V4 จริงแล้วกรอก
ตรวจบอร์ด | ข้อมูลทั่วไปของโมดูล ต้องตรวจกับป้าย/datasheet ของชิ้นจริง
ช่องว่างขีดเส้นแดง เช่น X = | mm คือค่าที่ไม่มีในแบบ ห้ามเดา ให้วัดจาก Robot V4 จริงแล้วกรอก และคัดลอกไปที่ภาค
ผนวก A

ข้อเท็จจริงสำ คัญก่อนอ่าน: Robot V4 เป็นหุ่นแข่ง (battlebot) อาวุธ beater แนวตั้ง ≈57 J ที่คนขับบังคับด้วยจอย Sensor ทั้ง 5 ตัวมีไว้ป้องกันตัวรถและช่วยคนขับ ได้แก่ รู้ว่ารถกลับหัว จำ กัดการเลี้ยว วัดรอบใบ วัดอุณหภูมิ และวัดแรงดันแบต V4 ไม่มี sensor วัดระยะ (LiDAR, Ultrasonic, ToF, IR, กล้อง, bumper, line, cliff, wheel encoder) ทั้งในแบบ CAD และเฟิร์มแวร์ หัวข้อที่ เขียนไว้สำ หรับ sensor วัดระยะจึงปรับเป็นเรื่องที่เทียบเท่าสำ หรับ V4 ดังนี้ §5 Coverage Map → แผนที่การรับรู้ของ sensor แต่ละตัว · §12 Blind Spot Test → ทดสอบการตรวจจับกลับหัวทุกมุม 0–315° · §13 Collision Safety Zone → เขตค่าเตือน ของ sensor และเขตอันตรายรอบใบ ถ้าต้องการเพิ่ม sensor วัดระยะในอนาคต ต้องออกแบบตำ แหน่งใหม่ใน CAD ก่อน

ความปลอดภัย: ทุกขั้นในคู่มือนี้ทำ ตอนถอดโรเตอร์ออก หรือเสียบหมุดล็อกใบไว้ ถอด removable link ก่อนบัดกรีหรือถอดสาย ทุกครั้ง การทดสอบที่ต้องหมุนอาวุธให้ทำ ในกล่องปิดเท่านั้น ตามแผนทดสอบใน robot_v4/STATUS.md

# @@H1@@1 วิเคราะห์ Robot V4

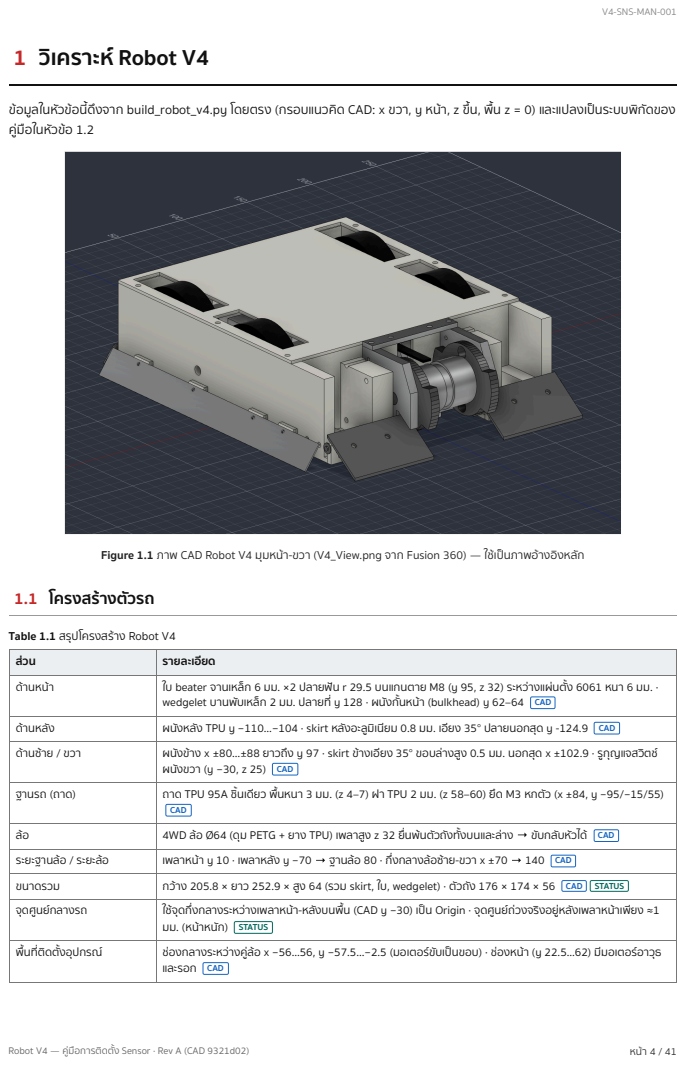
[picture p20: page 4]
Robot V4 — คู่มือการติดตั้ง Sensor · Rev A (CAD 9321d02)

ข้อมูลในหัวข้อนี้ดึงจาก build_robot_v4.py โดยตรง (กรอบแนวคิด CAD: x ขวา, y หน้า, z ขึ้น, พื้น z = 0) และแปลงเป็นระบบพิกัดของ
คู่มือในหัวข้อ 1.2

Figure 1.1 ภาพ CAD Robot V4 มุมหน้า-ขวา (V4_View.png จาก Fusion 360) — ใช้เป็นภาพอ้างอิงหลัก

@@H1.1@@1.1 โครงสร้างตัวรถ

Table 1.1 สรุปโครงสร้าง Robot V4

ส่วน | รายละเอียด
ด้านหน้า | ใบ beater จานเหล็ก 6 มม. ×2 ปลายฟัน r 29.5 บนแกนตาย M8 (y 95, z 32) ระหว่างแผ่นตั้ง 6061 หนา 6 มม. · wedgelet บานพับเหล็ก 2 มม. ปลายที่ y 128 · ผนังกั้นหน้า (bulkhead) y 62–64 CAD

ด้านหลัง | ผนังหลัง TPU y −110…−104 · skirt หลังอะลูมิเนียม 0.8 มม. เอียง 35° ปลายนอกสุด y -124.9 CAD
ด้านซ้าย / ขวา | ผนังข้าง x ±80…±88 ยาวถึง y 97 · skirt ข้างเอียง 35° ขอบล่างสูง 0.5 มม. นอกสุด x ±102.9 · รูกุญแจสวิตช์ ผนังขวา (y −30, z 25) CAD

ฐานรถ (ถาด) | ถาด TPU 95A ชิ้นเดียว พื้นหนา 3 มม. (z 4–7) ฝา TPU 2 มม. (z 58–60) ยึด M3 หกตัว (x ±84, y −95/−15/55) CAD

ล้อ | 4WD ล้อ Ø64 (ดุม PETG + ยาง TPU) เพลาสูง z 32 ยื่นพ้นตัวถังทั้งบนและล่าง → ขับกลับหัวได้ CAD
ระยะฐานล้อ / ระยะล้อ | เพลาหน้า y 10 · เพลาหลัง y −70 → ฐานล้อ 80 · กึ่งกลางล้อซ้าย-ขวา x ±70 → 140 CAD
ขนาดรวม | กว้าง 205.8 × ยาว 252.9 × สูง 64 (รวม skirt, ใบ, wedgelet) · ตัวถัง 176 × 174 × 56 CAD STATUS
จุดศูนย์กลางรถ | ใช้จุดกึ่งกลางระหว่างเพลาหน้า-หลังบนพื้น (CAD y −30) เป็น Origin · จุดศูนย์ถ่วงจริงอยู่หลังเพลาหน้าเพียง ≈1 มม. (หน้าหนัก) STATUS

พื้นที่ติดตั้งอุปกรณ์ | ช่องกลางระหว่างคู่ล้อ x −56…56, y −57.5…−2.5 (มอเตอร์ขับเป็นขอบ) · ช่องหน้า (y 22.5…62) มีมอเตอร์อาวุธ และรอก CAD

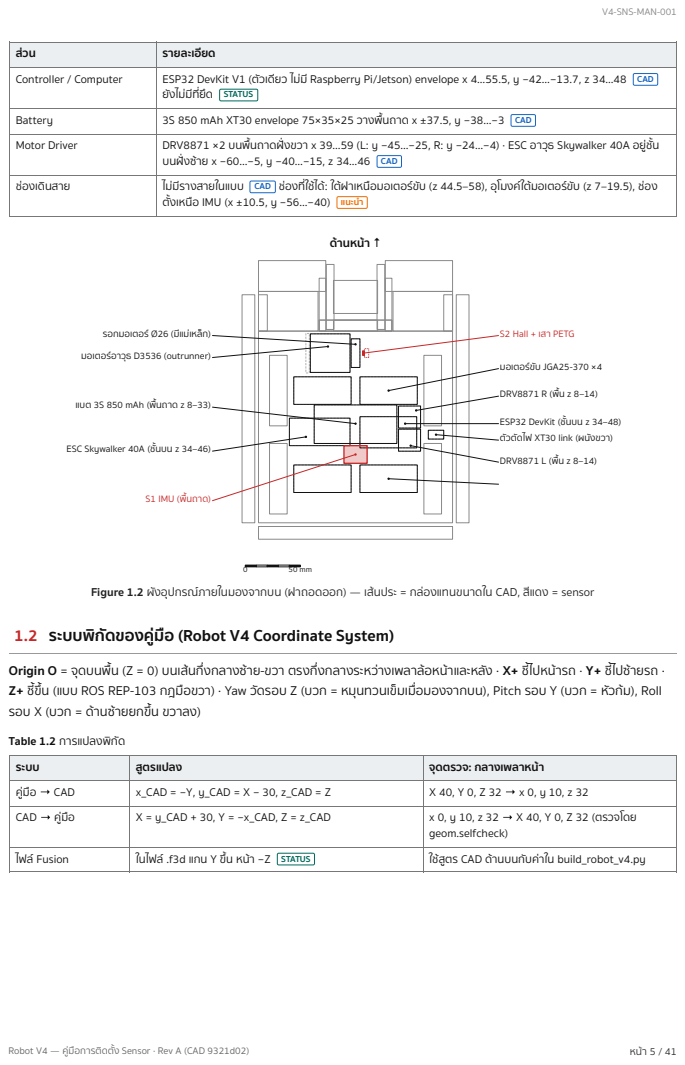
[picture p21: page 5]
Robot V4 — คู่มือการติดตั้ง Sensor · Rev A (CAD 9321d02); DRV8871 R (พื้น z 8–14); มอเตอร์ขับ JGA25-370 ×4; S1 IMU (พื้นถาด); ด้านหน้า ↑

ส่วน | รายละเอียด
Controller / Computer | ESP32 DevKit V1 (ตัวเดียว ไม่มี Raspberry Pi/Jetson) envelope x 4…55.5, y −42…−13.7, z 34…48 CAD ยังไม่มีที่ยึด STATUS

Battery | 3S 850 mAh XT30 envelope 75×35×25 วางพื้นถาด x ±37.5, y −38…−3 CAD
Motor Driver | DRV8871 ×2 บนพื้นถาดฝั่งขวา x 39…59 (L: y −45…−25, R: y −24…−4) · ESC อาวุธ Skywalker 40A อยู่ชั้น บนฝั่งซ้าย x −60…−5, y −40…−15, z 34…46 CAD

ช่องเดินสาย | ไม่มีรางสายในแบบ CAD ช่องที่ใช้ได้: ใต้ฝาเหนือมอเตอร์ขับ (z 44.5–58), อุโมงค์ใต้มอเตอร์ขับ (z 7–19.5), ช่อง ตั้งเหนือ IMU (x ±10.5, y −56…−40) แนะนำ

รอกมอเตอร์ Ø26 (มีแม่เหล็ก)
มอเตอร์อาวุธ D3536 (outrunner)

S2 Hall + เสา PETG

แบต 3S 850 mAh (พื้นถาด z 8–33)

ESP32 DevKit (ชั้นบน z 34–48)
ตัวตัดไฟ XT30 link (ผนังขวา)
DRV8871 L (พื้น z 8–14)

ESC Skywalker 40A (ชั้นบน z 34–46)

Figure 1.2 ผังอุปกรณ์ภายในมองจากบน (ฝาถอดออก) — เส้นประ = กล่องแทนขนาดใน CAD, สีแดง = sensor

@@H1.2@@1.2 ระบบพิกัดของคู่มือ (Robot V4 Coordinate System)

Origin O = จุดบนพื้น (Z = 0) บนเส้นกึ่งกลางซ้าย-ขวา ตรงกึ่งกลางระหว่างเพลาล้อหน้าและหลัง · X+ ชี้ไปหน้ารถ · Y+ ชี้ไปซ้ายรถ ·
Z+ ชี้ขึ้น (แบบ ROS REP-103 กฎมือขวา) · Yaw วัดรอบ Z (บวก = หมุนทวนเข็มเมื่อมองจากบน), Pitch รอบ Y (บวก = หัวก้ม), Roll
รอบ X (บวก = ด้านซ้ายยกขึ้น ขวาลง)
Table 1.2 การแปลงพิกัด

ระบบ | สูตรแปลง | จุดตรวจ: กลางเพลาหน้า
คู่มือ → CAD | x_CAD = −Y, y_CAD = X − 30, z_CAD = Z | X 40, Y 0, Z 32 → x 0, y 10, z 32
CAD → คู่มือ | X = y_CAD + 30, Y = −x_CAD, Z = z_CAD | x 0, y 10, z 32 → X 40, Y 0, Z 32 (ตรวจโดย geom.selfcheck)

ไฟล์ Fusion | ในไฟล์ .f3d แกน Y ขึ้น หน้า −Z STATUS | ใช้สูตร CAD ด้านบนกับค่าใน build_robot_v4.py

## ด้านหน้า (หัวรถ)

← ซ้าย | ขวา →

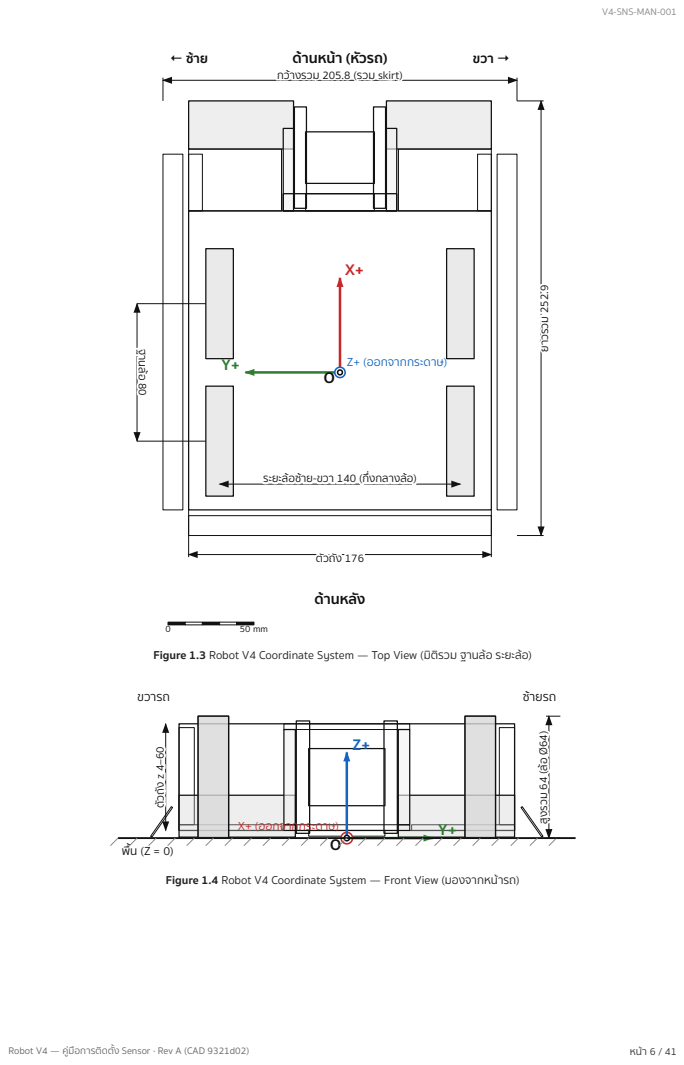
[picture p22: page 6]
Robot V4 — คู่มือการติดตั้ง Sensor · Rev A (CAD 9321d02); Z+ (ออกจากกระดาษ); ยาวรวม 252.9 ยาวรวม 252.9; ฐานล้อ 80 ฐานล้อ 80; ด้านหลัง; X+ (ออกจากกระดาษ); สูงรวม; (ล้อ Ø64) สูงรวม 64 (ล้อ Ø64); ขวารถ; ซ้ายรถ

กกว้ว้ว้าว้างงรรววมม 220055..88 ((รรววมม sskkiirrtt))

รระะยะ ยะล้ล้ล้อล้อซ้ซ้ซ้าซ้าย- ย-ขขววาา 114400 ((กึ่กึ่กึ่งกึ่งกกลลาางงล้ล้ล้อล้อ))

Figure 1.3 Robot V4 Coordinate System — Top View (มิติรวม ฐานล้อ ระยะล้อ)

Figure 1.4 Robot V4 Coordinate System — Front View (มองจากหน้ารถ)

X+

Z+

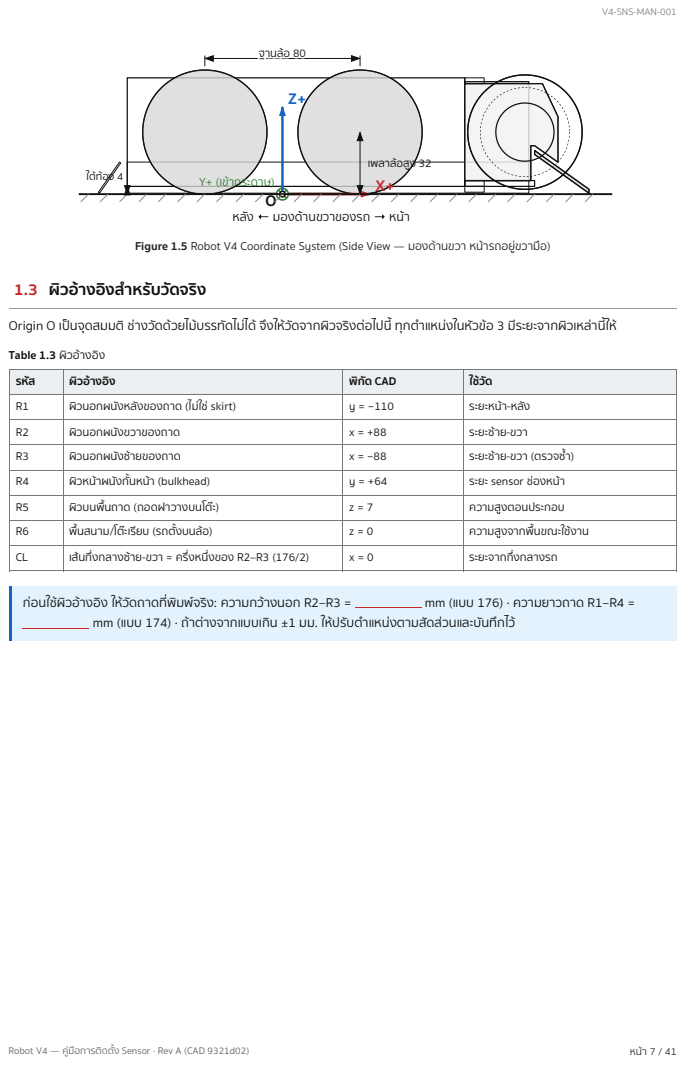
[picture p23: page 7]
Robot V4 — คู่มือการติดตั้ง Sensor · Rev A (CAD 9321d02); เพลาล้อสูง 32; ฐฐาานนล้ล้ล้อล้อ 8800; ก่อนใช้ผิวอ้างอิง ให้วัดถาดที่พิมพ์จริง: ความกว้างนอก R2–R3 =; mm (แบบ 176) · ความยาวถาด R1–R4 =

Y+ (เข้ากระดาษ)
หลัง ← มองด้านขวาของรถ → หน้า

Figure 1.5 Robot V4 Coordinate System (Side View — มองด้านขวา หน้ารถอยู่ขวามือ)

@@H1.3@@1.3 ผิวอ้างอิงสำ หรับวัดจริง

Origin O เป็นจุดสมมติ ช่างวัดด้วยไม้บรรทัดไม่ได้ จึงให้วัดจากผิวจริงต่อไปนี้ ทุกตำ แหน่งในหัวข้อ 3 มีระยะจากผิวเหล่านี้ให้
Table 1.3 ผิวอ้างอิง

รหัส | ผิวอ้างอิง | พิกัด CAD | ใช้วัด
R1 | ผิวนอกผนังหลังของถาด (ไม่ใช่ skirt) | y = −110 | ระยะหน้า-หลัง
R2 | ผิวนอกผนังขวาของถาด | x = +88 | ระยะซ้าย-ขวา
R3 | ผิวนอกผนังซ้ายของถาด | x = −88 | ระยะซ้าย-ขวา (ตรวจซ้ำ )
R4 | ผิวหน้าผนังกั้นหน้า (bulkhead) | y = +64 | ระยะ sensor ช่องหน้า
R5 | ผิวบนพื้นถาด (ถอดฝาวางบนโต๊ะ) | z = 7 | ความสูงตอนประกอบ
R6 | พื้นสนาม/โต๊ะเรียบ (รถตั้งบนล้อ) | z = 0 | ความสูงจากพื้นขณะใช้งาน
CL | เส้นกึ่งกลางซ้าย-ขวา = ครึ่งหนึ่งของ R2–R3 (176/2) | x = 0 | ระยะจากกึ่งกลางรถ

mm (แบบ 174) · ถ้าต่างจากแบบเกิน ±1 มม. ให้ปรับตำ แหน่งตามสัดส่วนและบันทึกไว้

# @@H2@@2 Sensor Layout Overview

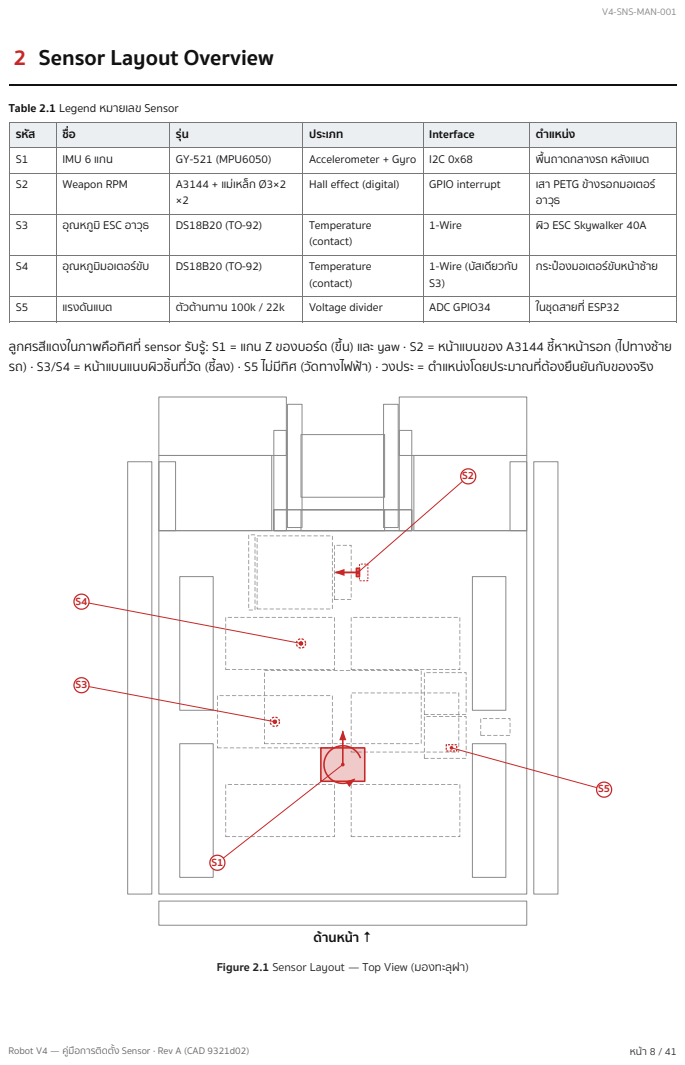
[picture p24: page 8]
Robot V4 — คู่มือการติดตั้ง Sensor · Rev A (CAD 9321d02); ด้านหน้า ↑

Table 2.1 Legend หมายเลข Sensor

รหัส | ชื่อ | รุ่น | ประเภท | Interface | ตำ แหน่ง
S1 | IMU 6 แกน | GY-521 (MPU6050) | Accelerometer + Gyro | I2C 0x68 | พื้นถาดกลางรถ หลังแบต
S2 | Weapon RPM | A3144 + แม่เหล็ก Ø3×2 ×2 | Hall effect (digital) | GPIO interrupt | เสา PETG ข้างรอกมอเตอร์ อาวุธ

S3 | อุณหภูมิ ESC อาวุธ | DS18B20 (TO-92) | Temperature (contact) | 1-Wire | ผิว ESC Skywalker 40A

S4 | อุณหภูมิมอเตอร์ขับ | DS18B20 (TO-92) | Temperature (contact) | 1-Wire (บัสเดียวกับ S3) | กระป๋องมอเตอร์ขับหน้าซ้าย

S5 | แรงดันแบต | ตัวต้านทาน 100k / 22k | Voltage divider | ADC GPIO34 | ในชุดสายที่ ESP32

ลูกศรสีแดงในภาพคือทิศที่ sensor รับรู้: S1 = แกน Z ของบอร์ด (ขึ้น) และ yaw · S2 = หน้าแบนของ A3144 ชี้หาหน้ารอก (ไปทางซ้าย
รถ) · S3/S4 = หน้าแบนแนบผิวชิ้นที่วัด (ชี้ลง) · S5 ไม่มีทิศ (วัดทางไฟฟ้า) · วงประ = ตำ แหน่งโดยประมาณที่ต้องยืนยันกับของจริง

Figure 2.1 Sensor Layout — Top View (มองทะลุฝา)

### มองจากด้านหน้า

### มองจากด้านหลัง

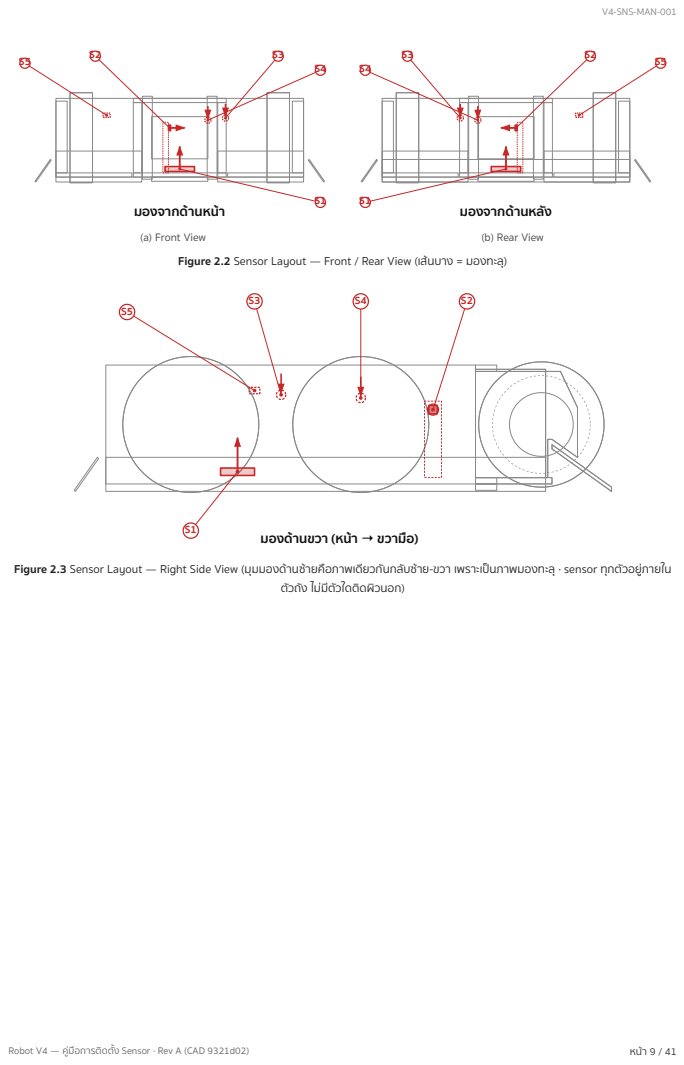
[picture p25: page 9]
Robot V4 — คู่มือการติดตั้ง Sensor · Rev A (CAD 9321d02); (b) Rear View

(a) Front View
Figure 2.2 Sensor Layout — Front / Rear View (เส้นบาง = มองทะลุ)

มองด้านขวา (หน้า → ขวามือ)

Figure 2.3 Sensor Layout — Right Side View (มุมมองด้านซ้ายคือภาพเดียวกันกลับซ้าย-ขวา เพราะเป็นภาพมองทะลุ · sensor ทุกตัวอยู่ภายใน

ตัวถัง ไม่มีตัวใดติดผิวนอก)

Robot V4 — คู่มือการติดตั้ง Sensor · Rev A (CAD 9321d02) | หน้า 10 / 41

# @@H3@@3 รายละเอียด Sensor แต่ละตัว

ตำ แหน่งอ้างอิงของแต่ละตัวระบุไว้ใต้ชื่อ ค่า X/Y/Z คำนวณจาก CAD ด้วย geom.py · ระยะทั้งหมดเป็น mm

## @@H3.1@@3.1 Sensor S1 — IMU (Upside-down + Yaw rate)

Table 3.1 S1 ข้อมูล Sensor

ชื่อ | รุ่น | ประเภท | หน้าที่
IMU 6 แกน | โมดูล GY-521 (ชิป MPU6050) บอร์ด 21×16 CAD | IMU (Accelerometer + Gyro) | (1) รู้ว่ารถกลับหัวแล้วกลับทิศคันเร่งเอง: az กรองแล้ว < −0.5 g ต่อเนื่อง 0.3 s (2) จำ กัดอัตราเลี้ยว ≤ 690°/s ขณะใบหมุน > 3,000 rpm FW

จุดอ้างอิง: กึ่งกลางผิวล่างของ PCB (ผิวที่แปะโฟม)

Table 3.2 S1 ตำ แหน่งและมุม
รายการ | ค่า (mm, °)
ตำ แหน่ง (คู่มือ) | X = -18 · Y = 0 · Z = 8 CAD
ตำ แหน่ง (CAD) | x = 0 · y = -48 · z = 8
ระยะจากพื้นสนาม (R6) | 8
ระยะจากผิวบนพื้นถาด (R5) | 1
ระยะจากขอบรถ | R1 ผนังหลังนอก 62 · R4 หน้าผนังกั้น 112 · R2 ผนังขวานอก 88 · R3 ผนังซ้ายนอก 88
ระยะจากกึ่งกลางรถ | จากเส้น CL 0 (อยู่บนเส้น) · จาก Origin O ในแนวราบ 18
มุมติดตั้ง | Yaw = 0° (ขอบบอร์ดขนานแกนรถ) · Pitch = 0° · Roll = 0°
ทิศที่ sensor หัน | ด้านชิ้นส่วน (มีชิป) หันขึ้น → แกน Z บอร์ดชี้ขึ้น = Z รถ · ตาม CAD ให้ลูกศร X บนบอร์ดชี้ไปขวารถ CAD (เฟิร์มแวร์ใช้แค่ az และ gz ทิศ X/Y ของบอร์ดจึงไม่มีผลต่อการทำ งาน — จดทิศจริง: ลูกศร X ชี้ )
ค่าวัดจริงหลังติดตั้ง วัดจริง | X = mm · Y = mm · Z = mm

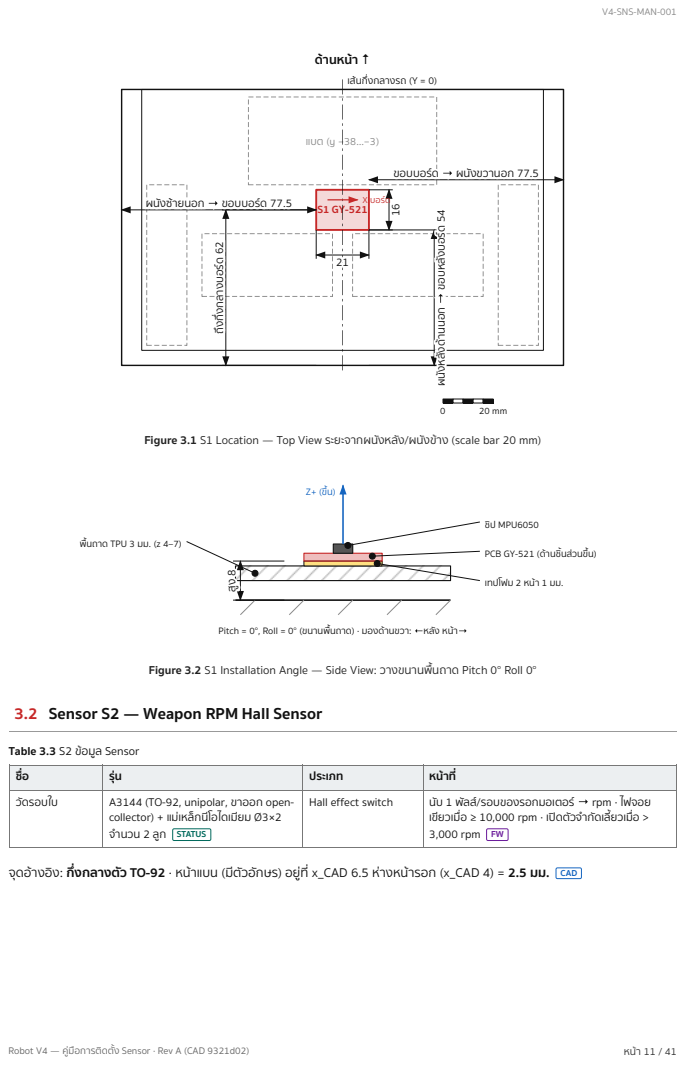
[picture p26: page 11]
Robot V4 — คู่มือการติดตั้ง Sensor · Rev A (CAD 9321d02); แบต (y −38…−3); ขอบหลังบอร์ด; ถึงกึ่งกลางบอร์ด; 62 ถึงกึ่งกลางบอร์ด 62; ผผนันันังนังซ้ซ้ซ้าซ้ายนยนออกก →→ ขขออบบบบออร์ร์ร์ดร์ด 7777..55; X บอร์ด; ชิป MPU6050

ด้านหน้า ↑
เส้นกึ่งกลางรถ (Y = 0)

ขขออบบบบออร์ร์ร์ดร์ด →→ ผผนันันังนังขขววาานนออกก 7777..55

54 ผนังหลังด้านนอก → ขอบหลังบอร์ด 54

ผนังหลังด้านนอก

Figure 3.1 S1 Location — Top View ระยะจากผนังหลัง/ผนังข้าง (scale bar 20 mm)

พื้นถาด TPU 3 มม. (z 4–7)

PCB GY-521 (ด้านชิ้นส่วนขึ้น)

เทปโฟม 2 หน้า 1 มม.

Pitch = 0°, Roll = 0° (ขนานพื้นถาด) · มองด้านขวา: ←หลัง หน้า→

Figure 3.2 S1 Installation Angle — Side View: วางขนานพื้นถาด Pitch 0° Roll 0°

@@H3.2@@3.2 Sensor S2 — Weapon RPM Hall Sensor

Table 3.3 S2 ข้อมูล Sensor

ชื่อ | รุ่น | ประเภท | หน้าที่
วัดรอบใบ | A3144 (TO-92, unipolar, ขาออก open-collector) + แม่เหล็กนีโอไดเมียม Ø3×2 จำ นวน 2 ลูก STATUS | Hall effect switch | นับ 1 พัลส์/รอบของรอกมอเตอร์ → rpm · ไฟจอย เขียวเมื่อ ≥ 10,000 rpm · เปิดตัวจำ กัดเลี้ยวเมื่อ > 3,000 rpm FW

จุดอ้างอิง: กึ่งกลางตัว TO-92 · หน้าแบน (มีตัวอักษร) อยู่ที่ x_CAD 6.5 ห่างหน้ารอก (x_CAD 4) = 2.5 มม. CAD

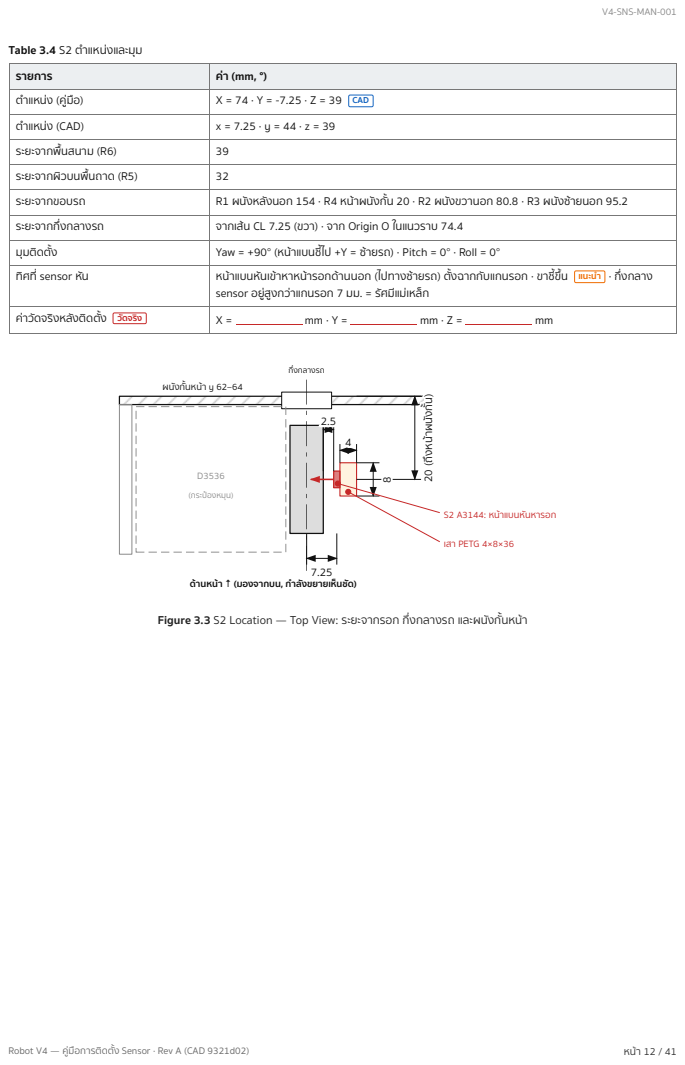
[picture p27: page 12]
Robot V4 — คู่มือการติดตั้ง Sensor · Rev A (CAD 9321d02); (กระป๋องหมุน); กึ่งกลางรถ; เสา PETG 4×8×36

Table 3.4 S2 ตำ แหน่งและมุม

รายการ | ค่า (mm, °)
ตำ แหน่ง (คู่มือ) | X = 74 · Y = -7.25 · Z = 39 CAD
ตำ แหน่ง (CAD) | x = 7.25 · y = 44 · z = 39
ระยะจากพื้นสนาม (R6) | 39
ระยะจากผิวบนพื้นถาด (R5) | 32
ระยะจากขอบรถ | R1 ผนังหลังนอก 154 · R4 หน้าผนังกั้น 20 · R2 ผนังขวานอก 80.8 · R3 ผนังซ้ายนอก 95.2
ระยะจากกึ่งกลางรถ | จากเส้น CL 7.25 (ขวา) · จาก Origin O ในแนวราบ 74.4
มุมติดตั้ง | Yaw = +90° (หน้าแบนชี้ไป +Y = ซ้ายรถ) · Pitch = 0° · Roll = 0°
ทิศที่ sensor หัน | หน้าแบนหันเข้าหาหน้ารอกด้านนอก (ไปทางซ้ายรถ) ตั้งฉากกับแกนรอก · ขาชี้ขึ้น แนะนำ · กึ่งกลาง sensor อยู่สูงกว่าแกนรอก 7 มม. = รัศมีแม่เหล็ก

ค่าวัดจริงหลังติดตั้ง วัดจริง | X = mm · Y = mm · Z = mm

ผนังกั้นหน้า y 62–64

(ถึงหน้าผนังกั้น) 20 (ถึงหน้าผนังกั้น)

S2 A3144: หน้าแบนหันหารอก

ด้านหน้า ↑ (มองจากบน, กำ ลังขยายเห็นชัด)

Figure 3.3 S2 Location — Top View: ระยะจากรอก กึ่งกลางรถ และผนังกั้นหน้า

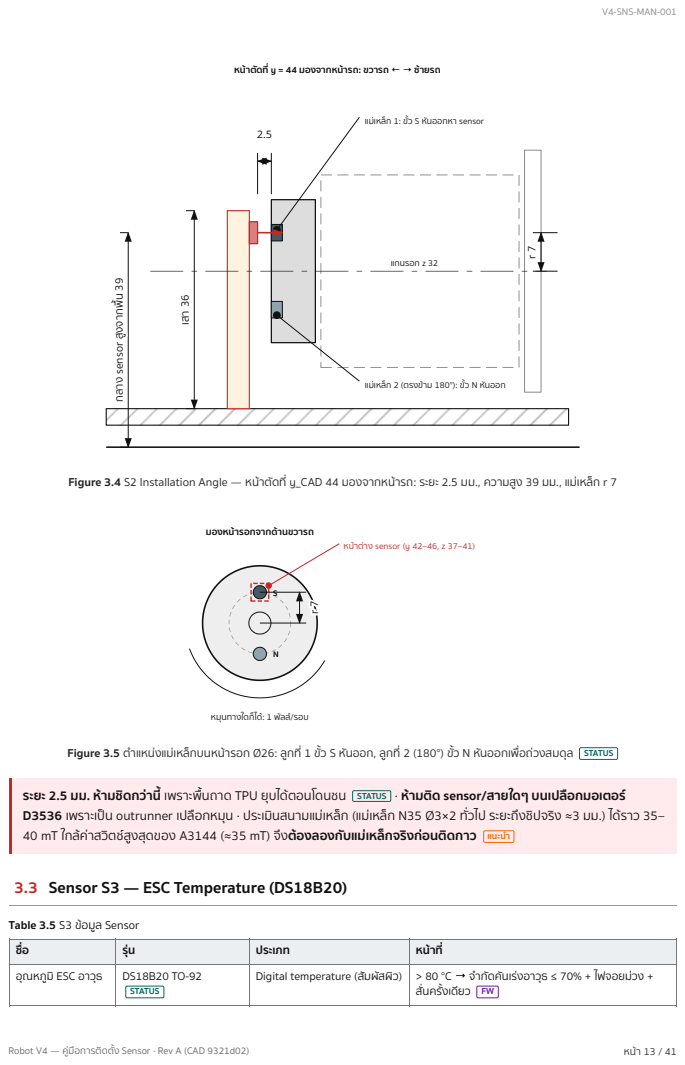
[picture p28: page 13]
Robot V4 — คู่มือการติดตั้ง Sensor · Rev A (CAD 9321d02); แกนรอก z 32; เสา 36 เสา 36

หน้าตัดที่ y = 44 มองจากหน้ารถ: ขวารถ ← → ซ้ายรถ

แม่เหล็ก 1: ขั้ว S หันออกหา sensor

กลาง sensor สูงจากพื้น 39

แม่เหล็ก 2 (ตรงข้าม 180°): ขั้ว N หันออก

Figure 3.4 S2 Installation Angle — หน้าตัดที่ y_CAD 44 มองจากหน้ารถ: ระยะ 2.5 มม., ความสูง 39 มม., แม่เหล็ก r 7

มองหน้ารอกจากด้านขวารถ

หน้าต่าง sensor (y 42–46, z 37–41)

หมุนทางใดก็ได้: 1 พัลส์/รอบ

Figure 3.5 ตำ แหน่งแม่เหล็กบนหน้ารอก Ø26: ลูกที่ 1 ขั้ว S หันออก, ลูกที่ 2 (180°) ขั้ว N หันออกเพื่อถ่วงสมดุล STATUS

ระยะ 2.5 มม. ห้ามชิดกว่านี้ เพราะพื้นถาด TPU ยุบได้ตอนโดนชน STATUS · ห้ามติด sensor/สายใดๆ บนเปลือกมอเตอร์
D3536 เพราะเป็น outrunner เปลือกหมุน · ประเมินสนามแม่เหล็ก (แม่เหล็ก N35 Ø3×2 ทั่วไป ระยะถึงชิปจริง ≈3 มม.) ได้ราว 35–
40 mT ใกล้ค่าสวิตช์สูงสุดของ A3144 (≈35 mT) จึงต้องลองกับแม่เหล็กจริงก่อนติดกาว แนะนำ

@@H3.3@@3.3 Sensor S3 — ESC Temperature (DS18B20)

Table 3.5 S3 ข้อมูล Sensor

ชื่อ | รุ่น | ประเภท | หน้าที่
อุณหภูมิ ESC อาวุธ | DS18B20 TO-92 STATUS | Digital temperature (สัมผัสผิว) | > 80 °C → จำ กัดคันเร่งอาวุธ ≤ 70% + ไฟจอยม่วง + สั่นครั้งเดียว FW

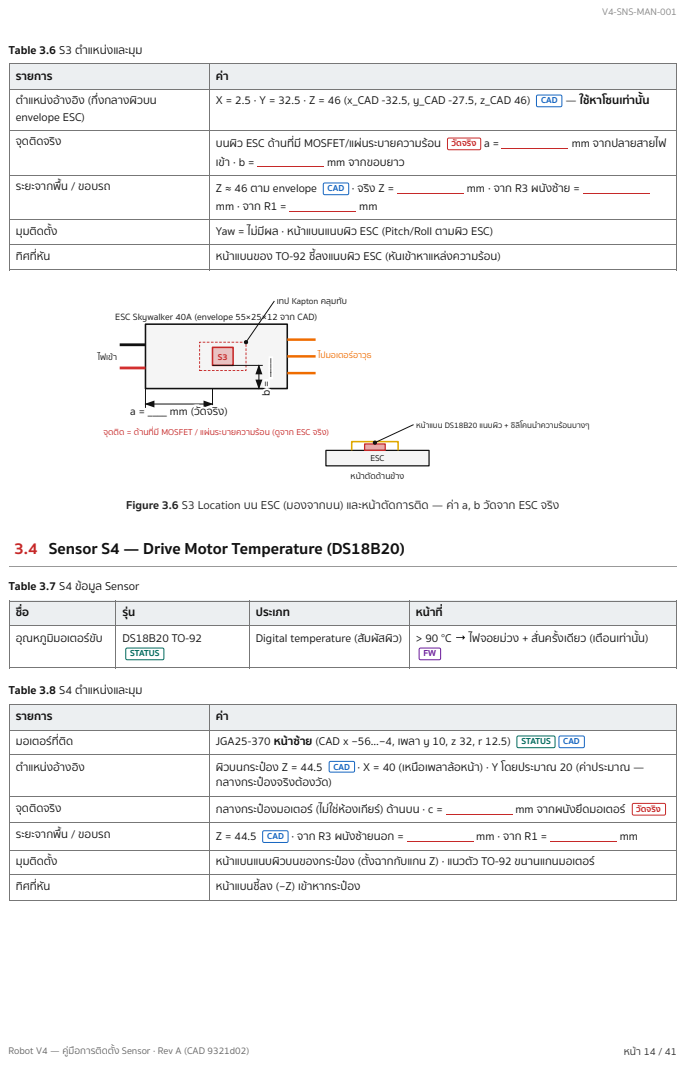
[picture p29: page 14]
Robot V4 — คู่มือการติดตั้ง Sensor · Rev A (CAD 9321d02); ไปมอเตอร์อาวุธ ไฟเข้า; ESC

Table 3.6 S3 ตำ แหน่งและมุม

รายการ | ค่า
ตำ แหน่งอ้างอิง (กึ่งกลางผิวบน envelope ESC) | X = 2.5 · Y = 32.5 · Z = 46 (x_CAD -32.5, y_CAD -27.5, z_CAD 46) CAD — ใช้หาโซนเท่านั้น

จุดติดจริง | บนผิว ESC ด้านที่มี MOSFET/แผ่นระบายความร้อน วัดจริง a = mm จากปลายสายไฟ เข้า · b = mm จากขอบยาว

ระยะจากพื้น / ขอบรถ | Z ≈ 46 ตาม envelope CAD · จริง Z = mm · จาก R3 ผนังซ้าย = mm · จาก R1 = mm

มุมติดตั้ง | Yaw = ไม่มีผล · หน้าแบนแนบผิว ESC (Pitch/Roll ตามผิว ESC)
ทิศที่หัน | หน้าแบนของ TO-92 ชี้ลงแนบผิว ESC (หันเข้าหาแหล่งความร้อน)

เทป Kapton คลุมทับ

ESC Skywalker 40A (envelope 55×25×12 จาก CAD)

aa == ________ mmmm ((วัวัวัดวัดจจริริริงริง))
จุดติด = ด้านที่มี MOSFET / แผ่นระบายความร้อน (ดูจาก ESC จริง)

หน้าแบน DS18B20 แนบผิว + ซิลิโคนนำ ความร้อนบางๆ

หน้าตัดด้านข้าง

Figure 3.6 S3 Location บน ESC (มองจากบน) และหน้าตัดการติด — ค่า a, b วัดจาก ESC จริง

@@H3.4@@3.4 Sensor S4 — Drive Motor Temperature (DS18B20)

Table 3.7 S4 ข้อมูล Sensor

ชื่อ | รุ่น | ประเภท | หน้าที่
อุณหภูมิมอเตอร์ขับ | DS18B20 TO-92 STATUS | Digital temperature (สัมผัสผิว) | > 90 °C → ไฟจอยม่วง + สั่นครั้งเดียว (เตือนเท่านั้น) FW

Table 3.8 S4 ตำ แหน่งและมุม

มอเตอร์ที่ติด | JGA25-370 หน้าซ้าย (CAD x −56…−4, เพลา y 10, z 32, r 12.5) STATUS CAD
ตำ แหน่งอ้างอิง | ผิวบนกระป๋อง Z = 44.5 CAD · X = 40 (เหนือเพลาล้อหน้า) · Y โดยประมาณ 20 (ค่าประมาณ — กลางกระป๋องจริงต้องวัด)

จุดติดจริง | กลางกระป๋องมอเตอร์ (ไม่ใช่ห้องเกียร์) ด้านบน · c = mm จากผนังยึดมอเตอร์ วัดจริง
ระยะจากพื้น / ขอบรถ | Z = 44.5 CAD · จาก R3 ผนังซ้ายนอก = mm · จาก R1 = mm
มุมติดตั้ง | หน้าแบนแนบผิวบนของกระป๋อง (ตั้งฉากกับแกน Z) · แนวตัว TO-92 ขนานแกนมอเตอร์
ทิศที่หัน | หน้าแบนชี้ลง (−Z) เข้าหากระป๋อง

Robot V4 — คู่มือการติดตั้ง Sensor · Rev A (CAD 9321d02) | หน้า 15 / 41

ผนังยึดมอเตอร์

กระป๋องมอเตอร์ 370 | เกียร์

รอยต่อเกียร์/กระป๋อง = ____ mm จากผนัง (วัดจริง)

S4

cc == ________ mmmm ((วัวัวัดวัดจจริริริงริง))

z 44.5

(CAD) z 44.5 (CA
D)

มอเตอร์ขับหน้าซ้าย มองจากหน้ารถ (ซ้ายรถอยู่ขวามือ) ห้ามติดบนมอเตอร์อาวุธ D3536: กระป๋องหมุน

Figure 3.7 S4 Location บนมอเตอร์ขับหน้าซ้าย มองจากหน้ารถ

## @@H3.5@@3.5 Sensor S5 — Battery Voltage Divider

Table 3.9 S5 ข้อมูล Sensor

ชื่อ | รุ่น | ประเภท | หน้าที่
แรงดันแบต 3S | ตัวต้านทาน 100 kΩ + 22 kΩ (แนะนำ 1%, 1/4 W) STATUS | Voltage divider → ADC | < 10.5 V นานเกิน 2 s → ไฟจอยแดง + สั่น · หายเมื่อ > 10.9 V · ไม่สนใจค่า < 5 V (เสียบ USB อย่างเดียว) FW

Table 3.10 S5 ตำ แหน่ง
รายการ | ค่า
ตำ แหน่ง | ต่ออยู่ในชุดสายที่ปลาย ESP32 ใกล้ขา GPIO34 STATUS — ไม่มีพิกัดตายตัว · ดูสี่เหลี่ยมประ S5 ใน Figure 2.1 (มุมหลัง-ขวาของ ESP32)
จุดรับไฟ | หลัง removable link และฟิวส์ เพื่อไม่ให้ดูดแบตตอนถอด link (กระแสผ่าน ≈ 11.1 V / 122 kΩ ≈ 0.09 mA) แนะนำ
มุม/ทิศ | ไม่มีผล (วัดทางไฟฟ้า) · หุ้มท่อหดทั้งชุด ยึดติดชุดสาย ไม่ให้ขาตัวต้านทานรับแรงสั่น

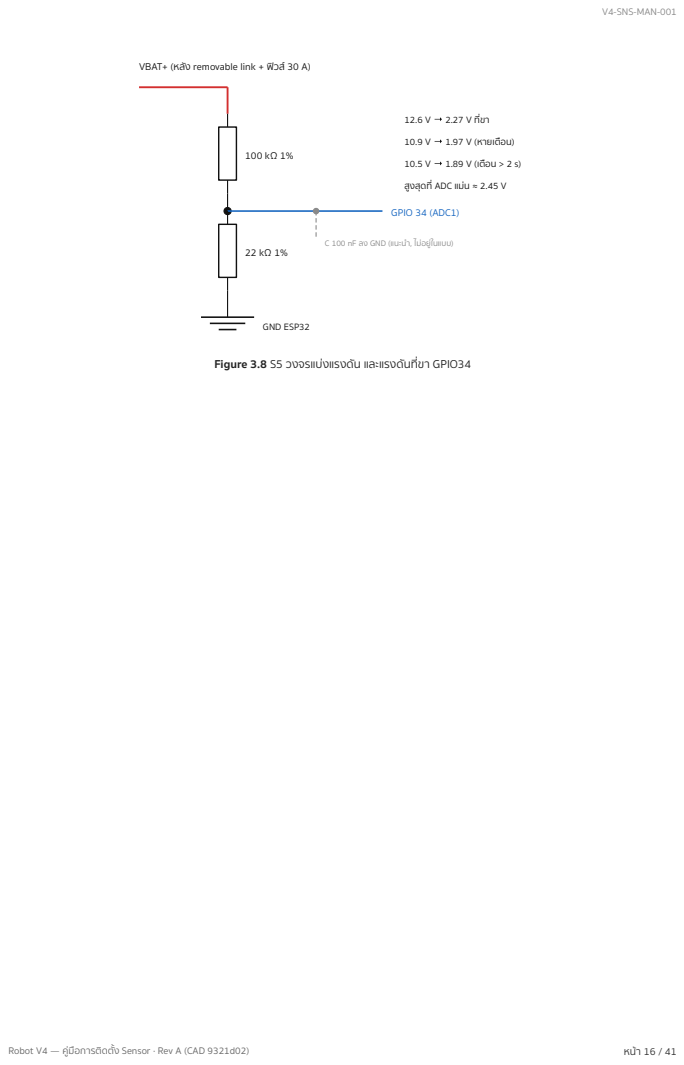
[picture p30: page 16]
Robot V4 — คู่มือการติดตั้ง Sensor · Rev A (CAD 9321d02); GND ESP32

VBAT+ (หลัง removable link + ฟิวส์ 30 A)

10.9 V → 1.97 V (หายเตือน)
สูงสุดที่ ADC แม่น ≈ 2.45 V
GPIO 34 (ADC1)

C 100 nF ลง GND (แนะนำ , ไม่อยู่ในแบบ)

Figure 3.8 S5 วงจรแบ่งแรงดัน และแรงดันที่ขา GPIO34

Robot V4 — คู่มือการติดตั้ง Sensor · Rev A (CAD 9321d02) | หน้า 17 / 41

# @@H4@@4 เหตุผลในการเลือกตำแหน่ง

หลักร่วมของทุกตัว STATUS : อยู่ในช่องกลางรถ ห่างโซนรับแรงชนด้านหน้า ยกเว้น S2 ที่ต้องอยู่ติดรอก · ไม่มีตัวใดจำ เป็นต่อการขับ ถ้าเสียหรือหลุด รถยังขับได้และฟังก์ชันนั้นกลับไปทำ งานแบบเดิม (เช่น สลับกลับหัวด้วยปุ่ม Y เอง)
Table 4.1 เหตุผลของตำ แหน่งและขอบเขตการรับรู้
Sensor | เหตุผลทางวิศวกรรม | Field of View / ขอบเขตการรับรู้
S1 IMU | • กลางรถ (Y = 0) และอยู่ระหว่างเพลา จึงห่างจุดกระแทก (หน้า/ข้าง) ที่สุด ค่า az ไม่ถูกแรงชนกระชากมาก • วางบนพื้นถาดซึ่งเป็นระนาบอ้างอิงของรถ → แกน Z บอร์ดตรงกับ Z รถโดยไม่ ต้องปรับมุม • โฟม 1 มม. ลดการสั่นความถี่สูงจากใบ 12,400 rpm (≈207 Hz) ที่ทำ ให้ accelerometer อิ่มตัว • ห่างมอเตอร์อาวุธและ ESC (MPU6050 ไม่มี magnetometer จึงไม่ถูกแม่เหล็ก รบกวน แต่สายสัญญาณยังเก็บ noise ได้) • gyro วัด yaw rate ได้เท่ากันทุกจุดบนวัตถุแข็ง ตำ แหน่งจึงไม่มีผลต่อการจำ กัด เลี้ยว | ไม่มีกรวยมองเห็น: วัดความเร่งและอัตราหมุน ของทั้งตัวรถ · ช่วงที่ตั้งในเฟิร์มแวร์ ±16 g, ±2000 °/s FW
S2 Hall | • ต้องอยู่ห่างแม่เหล็กบนหน้ารอก 2.5 มม. (ใกล้พอให้สวิตช์ ไกลพอไม่ให้รอกตีเมื่อ พื้น TPU ยุบ) • วางฝั่งรอก (+x_CAD) ตรงข้ามกับมอเตอร์ จึงอยู่ห่างแม่เหล็กภายในมอเตอร์ D3536 อย่างน้อย 11.5 มม. • ความสูง 39 = แกนรอก 32 + รัศมีแม่เหล็ก 7 → แม่เหล็กผ่านกึ่งกลาง sensor พอดี • อยู่หลังผนังกั้นหน้า จึงไม่โดนใบ/คู่ต่อสู้โดยตรง | ตรวจจับเฉพาะเมื่อแม่เหล็กขั้ว S ผ่านหน้าแบน ในระยะไม่กี่มิลลิเมตร → 1 พัลส์ต่อรอบ · แม่ เหล็กลูกที่ 2 (ขั้ว N) ไม่ทำ ให้สวิตช์
S3 ESC temp | • ติดที่ ESC อาวุธซึ่งไม่มีตัวจำ กัดกระแส และอาจรับกระแสชั่วขณะ ≈110 A หลัง โดนชน STATUS • ESC อยู่ชั้นบนใต้ฝา เข้าถึงได้ง่าย สายสั้น | วัดเฉพาะจุดที่สัมผัส (ไม่ใช่อุณหภูมิเฉลี่ยของ ESC) → ต้องติดตรงจุดร้อนที่สุด
S4 Motor temp | • มอเตอร์ขับหน้าซ้ายรับภาระมากเพราะรถหน้าหนัก (CG อยู่หลังเพลาหน้า ≈1 มม.) STATUS • ด้านบนกระป๋องว่างถึงฝา 13.5 มม. ติดง่าย ไม่ชนชิ้นอื่น • ห้ามติดมอเตอร์อาวุธ (เปลือกหมุน) | วัด 1 ใน 4 มอเตอร์ → มอเตอร์อีก 3 ตัวเป็น blind spot (ดู §5)
S5 Divider | • ต่อใกล้ขา GPIO34 ให้จุดกลาง (อิมพีแดนซ์สูง) สั้นที่สุด ลด noise • ใช้ ADC1 เพราะ ADC2 ใช้ไม่ได้ขณะเปิดบลูทูธ STATUS | 12.6 V → 2.27 V อยู่ในช่วงแม่นของ ADC (≤ ≈2.45 V)

## @@H4.1@@4.1 เทียบกับเกณฑ์ทั่วไปของหุ่นยนต์เคลื่อนที่

Table 4.2 เกณฑ์การเลือกตำ แหน่งที่ใช้/ไม่ใช้กับ V4
เกณฑ์ทั่วไป | ใช้กับ V4? | คำ อธิบาย
ลด blind spot / ตรวจจับผนัง โต๊ะ ขาเก้าอี้ วัตถุระดับ พื้น สิ่งกีดขวางด้านข้าง | ไม่ใช้ | ไม่มี sensor วัดระยะ คนขับมองสนามเอง
ป้องกันล้อชนวัตถุ | ไม่ใช้ | หุ่นแข่งตั้งใจชน ตัวถัง TPU และ skirt รับแรงแทน
ลดสัญญาณรบกวน | ใช้ | แยกโซนสายกำ ลัง/สัญญาณ, ดึงขึ้น 3.3 V, กรองค่าในเฟิร์มแวร์ (§8)
ลดการสะท้อนจากพื้น | ไม่ใช้ | ไม่มี sensor แสง/เสียง
ป้องกัน sensor มองเห็นตัวรถเอง | เทียบได้ | S2 ต้องไม่สวิตช์จากแม่เหล็กในมอเตอร์ D3536 หรือสายมอเตอร์ → ทดสอบ T6 (§11)
ป้องกัน sensor จากแรงกระแทก | ใช้ (สำ คัญที่สุด) | ทุกตัวอยู่ในตัวถัง ห่างจุดชน, IMU บนโฟม, เฟิร์มแวร์กรองค่า 0.15 s + ค้าง 0.3 s

# @@H5@@5 Sensor Coverage Map (ฉบับ V4)

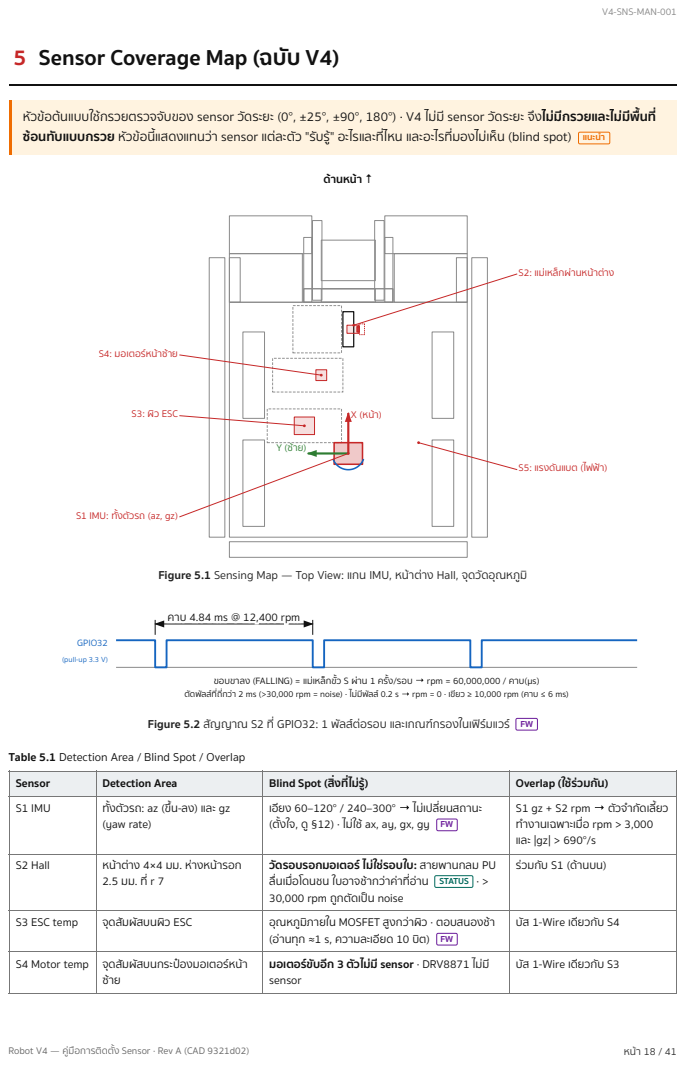
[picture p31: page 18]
Robot V4 — คู่มือการติดตั้ง Sensor · Rev A (CAD 9321d02); S3: ผิว ESC; ด้านหน้า ↑; GPIO32; (pull-up 3.3 V); Figure 5.2 สัญญาณ S2 ที่ GPIO32: 1 พัลส์ต่อรอบ และเกณฑ์กรองในเฟิร์มแวร์

หัวข้อต้นแบบใช้กรวยตรวจจับของ sensor วัดระยะ (0°, ±25°, ±90°, 180°) · V4 ไม่มี sensor วัดระยะ จึงไม่มีกรวยและไม่มีพื้นที่
ซ้อนทับแบบกรวย หัวข้อนี้แสดงแทนว่า sensor แต่ละตัว "รับรู้" อะไรและที่ไหน และอะไรที่มองไม่เห็น (blind spot) แนะนำ

S2: แม่เหล็กผ่านหน้าต่าง

S4: มอเตอร์หน้าซ้าย

S5: แรงดันแบต (ไฟฟ้า)

S1 IMU: ทั้งตัวรถ (az, gz)

Figure 5.1 Sensing Map — Top View: แกน IMU, หน้าต่าง Hall, จุดวัดอุณหภูมิ

คคาาบบ 44..8844 mmss @@ 1122,,440000 rprpmm

ขอบขาลง (FALLING) = แม่เหล็กขั้ว S ผ่าน 1 ครั้ง/รอบ → rpm = 60,000,000 / คาบ(µs)
ตัดพัลส์ที่ถี่กว่า 2 ms (>30,000 rpm = noise) · ไม่มีพัลส์ 0.2 s → rpm = 0 · เขียว ≥ 10,000 rpm (คาบ ≤ 6 ms)

Table 5.1 Detection Area / Blind Spot / Overlap

Sensor | Detection Area | Blind Spot (สิ่งที่ไม่รู้) | Overlap (ใช้ร่วมกัน)
S1 IMU | ทั้งตัวรถ: az (ขึ้น-ลง) และ gz (yaw rate) | เอียง 60–120° / 240–300° → ไม่เปลี่ยนสถานะ (ตั้งใจ, ดู §12) · ไม่ใช้ ax, ay, gx, gy FW | S1 gz + S2 rpm → ตัวจำ กัดเลี้ยว ทำ งานเฉพาะเมื่อ rpm > 3,000 และ |gz| > 690°/s

S2 Hall | หน้าต่าง 4×4 มม. ห่างหน้ารอก 2.5 มม. ที่ r 7 | วัดรอบรอกมอเตอร์ ไม่ใช่รอบใบ: สายพานกลม PU ลื่นเมื่อโดนชน ใบอาจช้ากว่าค่าที่อ่าน STATUS · > 30,000 rpm ถูกตัดเป็น noise | ร่วมกับ S1 (ด้านบน)

S3 ESC temp | จุดสัมผัสบนผิว ESC | อุณหภูมิภายใน MOSFET สูงกว่าผิว · ตอบสนองช้า (อ่านทุก ≈1 s, ความละเอียด 10 บิต) FW | บัส 1-Wire เดียวกับ S4

S4 Motor temp | จุดสัมผัสบนกระป๋องมอเตอร์หน้า ซ้าย | มอเตอร์ขับอีก 3 ตัวไม่มี sensor · DRV8871 ไม่มี sensor | บัส 1-Wire เดียวกับ S3

Robot V4 — คู่มือการติดตั้ง Sensor · Rev A (CAD 9321d02) | หน้า 19 / 41
S5 Divider | แรงดันหลัง link/ฟิวส์ | ไม่มีการวัดกระแส (ใช้ watt meter ตอนทดสอบบนโต๊ะ แทน) STATUS · แรงดันตกสั้นกว่า 2 s ไม่เตือน | —

# @@H6@@6 Mechanical Installation

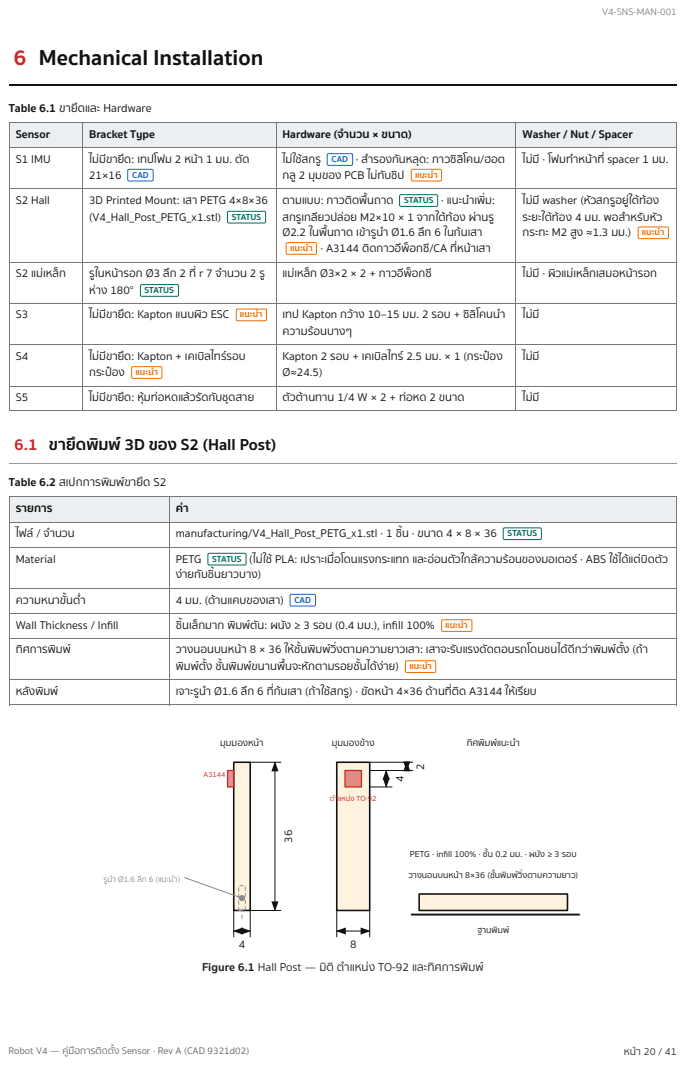
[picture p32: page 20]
Robot V4 — คู่มือการติดตั้ง Sensor · Rev A (CAD 9321d02); มุมมองหน้า; Ø1.6 ลึก 6 (แนะนำ ); มุมมองข้าง; ฐานพิมพ์

Table 6.1 ขายึดและ Hardware

Sensor | Bracket Type | Hardware (จำ นวน × ขนาด) | Washer / Nut / Spacer
S1 IMU | ไม่มีขายึด: เทปโฟม 2 หน้า 1 มม. ตัด 21×16 CAD | ไม่ใช้สกรู CAD · สำ รองกันหลุด: กาวซิลิโคน/ฮอต กลู 2 มุมของ PCB ไม่ทับชิป แนะนำ | ไม่มี · โฟมทำ หน้าที่ spacer 1 มม.

S2 Hall | 3D Printed Mount: เสา PETG 4×8×36 (V4_Hall_Post_PETG_x1.stl) STATUS | ตามแบบ: กาวติดพื้นถาด STATUS · แนะนำ เพิ่ม: สกรูเกลียวปล่อย M2×10 × 1 จากใต้ท้อง ผ่านรู Ø2.2 ในพื้นถาด เข้ารูนำ Ø1.6 ลึก 6 ในก้นเสา แนะนำ · A3144 ติดกาวอีพ็อกซี/CA ที่หน้าเสา | ไม่มี washer (หัวสกรูอยู่ใต้ท้อง ระยะใต้ท้อง 4 มม. พอสำ หรับหัว กระทะ M2 สูง ≈1.3 มม.) แนะนำ

S2 แม่เหล็ก | รูในหน้ารอก Ø3 ลึก 2 ที่ r 7 จำ นวน 2 รู ห่าง 180° STATUS | แม่เหล็ก Ø3×2 × 2 + กาวอีพ็อกซี | ไม่มี · ผิวแม่เหล็กเสมอหน้ารอก

S3 | ไม่มีขายึด: Kapton แนบผิว ESC แนะนำ | เทป Kapton กว้าง 10–15 มม. 2 รอบ + ซิลิโคนนำ ความร้อนบางๆ | ไม่มี

S4 | ไม่มีขายึด: Kapton + เคเบิลไทร์รอบ กระป๋อง แนะนำ | Kapton 2 รอบ + เคเบิลไทร์ 2.5 มม. × 1 (กระป๋อง Ø≈24.5) | ไม่มี

S5 | ไม่มีขายึด: หุ้มท่อหดแล้วรัดกับชุดสาย | ตัวต้านทาน 1/4 W × 2 + ท่อหด 2 ขนาด | ไม่มี

@@H6.1@@6.1 ขายึดพิมพ์ 3D ของ S2 (Hall Post)

Table 6.2 สเปกการพิมพ์ขายึด S2

รายการ | ค่า
ไฟล์ / จำ นวน | manufacturing/V4_Hall_Post_PETG_x1.stl · 1 ชิ้น · ขนาด 4 × 8 × 36 STATUS
Material | PETG STATUS (ไม่ใช้ PLA: เปราะเมื่อโดนแรงกระแทก และอ่อนตัวใกล้ความร้อนของมอเตอร์ · ABS ใช้ได้แต่บิดตัว ง่ายกับชิ้นยาวบาง)

ความหนาขั้นต่ำ | 4 มม. (ด้านแคบของเสา) CAD
Wall Thickness / Infill | ชิ้นเล็กมาก พิมพ์ตัน: ผนัง ≥ 3 รอบ (0.4 มม.), infill 100% แนะนำ
ทิศการพิมพ์ | วางนอนบนหน้า 8 × 36 ให้ชั้นพิมพ์วิ่งตามความยาวเสา: เสาจะรับแรงดัดตอนรถโดนชนได้ดีกว่าพิมพ์ตั้ง (ถ้า พิมพ์ตั้ง ชั้นพิมพ์ขนานพื้นจะหักตามรอยชั้นได้ง่าย) แนะนำ

หลังพิมพ์ | เจาะรูนำ Ø1.6 ลึก 6 ที่ก้นเสา (ถ้าใช้สกรู) · ขัดหน้า 4×36 ด้านที่ติด A3144 ให้เรียบ

ทิศพิมพ์แนะนำ

ตำ แหน่ง TO-92

PETG · infill 100% · ชั้น 0.2 มม. · ผนัง ≥ 3 รอบ
วางนอนบนหน้า 8×36 (ชั้นพิมพ์วิ่งตามความยาว)

Figure 6.1 Hall Post — มิติ ตำ แหน่ง TO-92 และทิศการพิมพ์

Robot V4 — คู่มือการติดตั้ง Sensor · Rev A (CAD 9321d02) | หน้า 21 / 41

พื้นถาด TPU 95A (z 4–7)

เทปโฟม 2 หน้า 1 มม. (21×16)

PCB GY-521 1.6 มม.

MPU6050

กาวซิลิโคน/ฮอตกลู 2 มุม (แนะนำ สำ รองกันหลุด)

Z+

ภาพขยายแนวตั้ง ×3 (ไม่ตามสเกล)
Figure 6.2 ชั้นการติด S1 (IMU) บนพื้นถาด

ผิวชิ้นส่วน (ESC / กระป๋องมอเตอร์)

ซิลิโคนนำ ความร้อนบางๆ | DS18B20 | Kapton กว้าง 10–15 มม. 2 รอบ

ท่อหด 3 เส้นแยก + ท่อหดรวม

หน้าแบน (มีตัวอักษร) แนบผิว · มอเตอร์: รัดเพิ่มด้วยเคเบิลไทร์ 1 เส้น

Figure 6.3 การติด DS18B20 ของ S3/S4

## @@H6.2@@6.2 การใส่แม่เหล็ก S2 และตรวจขั้ว

1. ต่อ A3144 ชั่วคราวบนโต๊ะ: ขา 1 → 5 V, ขา 2 → GND, ขา 3 → ตัวต้านทาน 10k ขึ้น 3.3 V และวัดขา 3 ด้วยมัลติมิเตอร์
2. จ่อหน้าแม่เหล็กทีละหน้าเข้าหาหน้าแบนของ A3144: หน้าที่ทำ ให้ขา 3 ตกเป็น ≈0 V คือขั้ว S ทำ เครื่องหมายด้วยปากกา
3. กดแม่เหล็กลูกที่ 1 เข้ารู ให้ขั้ว S หันออก · ลูกที่ 2 (รูตรงข้าม 180°) ให้ขั้ว N หันออก STATUS หยอดอีพ็อกซีรอบขอบ รอให้แห้ง ตามเวลาของกาว
4. ตรวจซ้ำ : หมุนรอกช้าๆ หนึ่งรอบ ขา 3 ต้องตกครั้งเดียวต่อรอบ
แรงเหวี่ยงบนแม่เหล็ก 1 ลูก (มวล ≈0.11 g) ที่รอบตัวเปล่า 13,781 rpm STATUS ≈ 1.5 N ในแนวรัศมี ซึ่งผนังรูรับไว้ กาวรับเพียงแรง ในแนวแกน

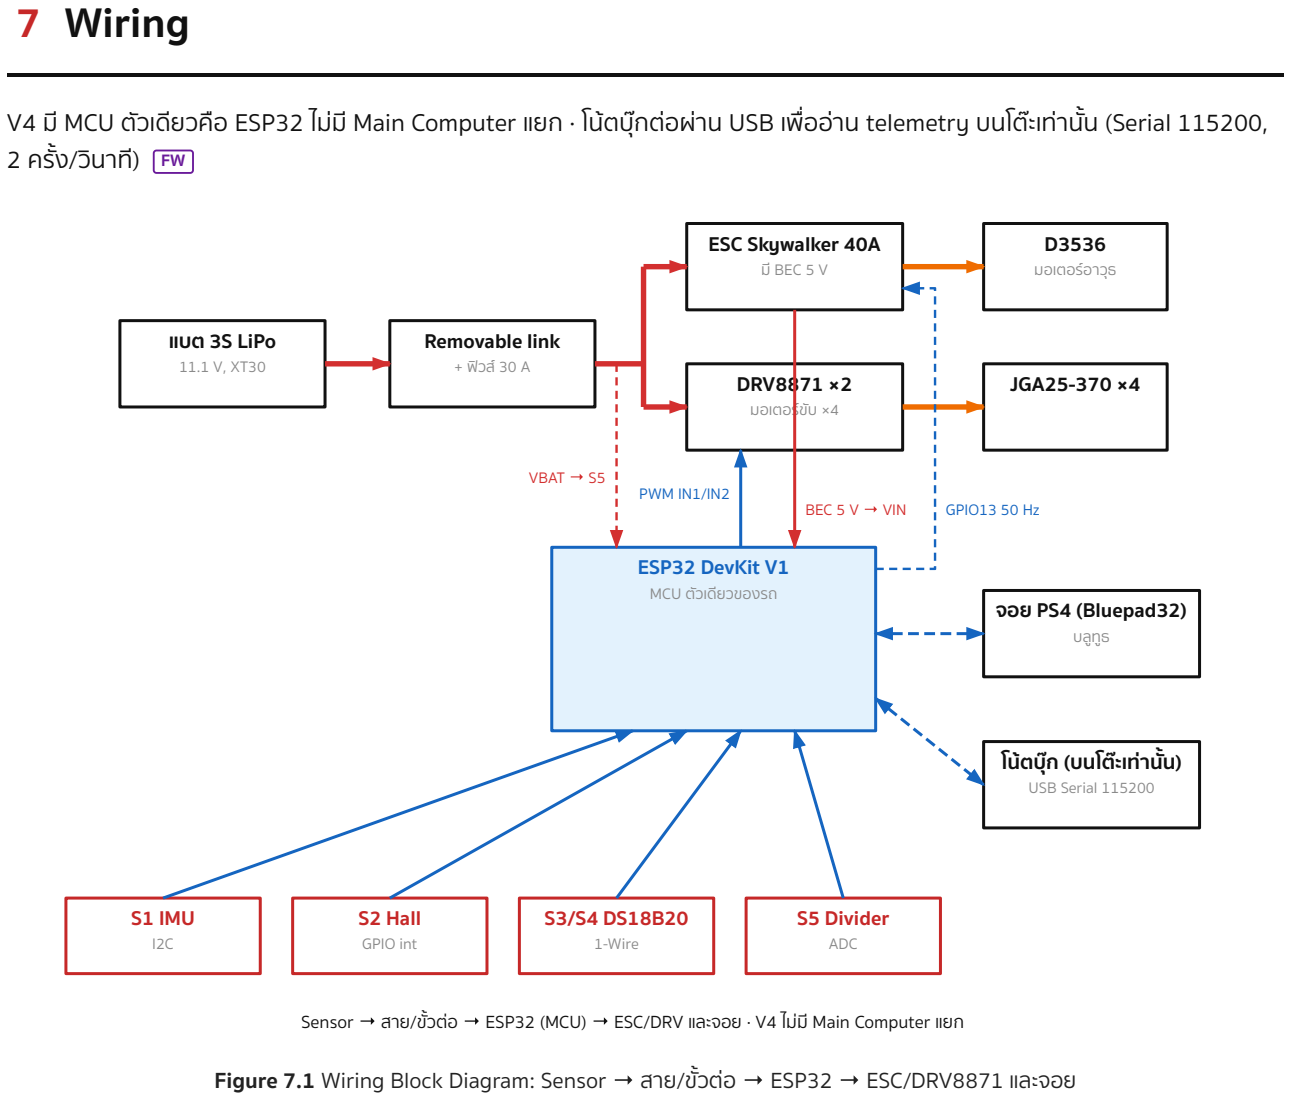
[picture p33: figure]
@@H7@@7 Wiring; 2 ครั้ง/วินาที) FW; แบต 3S LiPo 11.1 V, XT30; Removable link + ฟิวส์ 30 A; ESC Skywalker 40A มี BEC 5 V; DRV8871 ×2 มอเตอร์ขับ ×4; D3536 มอเตอร์อาวุธ; JGA25-370 ×4; ESP32 DevKit V1 MCU ตัวเดียวของรถ; S1 IMU I2C; S2 Hall GPIO int; S3/S4 DS18B20 1-Wire; S5 Divider ADC; VBAT → S5; BEC 5 V → VIN; PWM IN1/IN2; GPIO13 50 Hz; จอย PS4 (Bluepad32); โน้ตบุ๊ก (บนโต๊ะเท่านั้น) USB Serial 115200

Robot V4 — คู่มือการติดตั้ง Sensor · Rev A (CAD 9321d02) | หน้า 22 / 41

V4 มี MCU ตัวเดียวคือ ESP32 ไม่มี Main Computer แยก · โน้ตบุ๊กต่อผ่าน USB เพื่ออ่าน telemetry บนโต๊ะเท่านั้น (Serial 115200,

Sensor → สาย/ขั้วต่อ → ESP32 (MCU) → ESC/DRV และจอย · V4 ไม่มี Main Computer แยก
Figure 7.1 Wiring Block Diagram: Sensor → สาย/ขั้วต่อ → ESP32 → ESC/DRV8871 และจอย

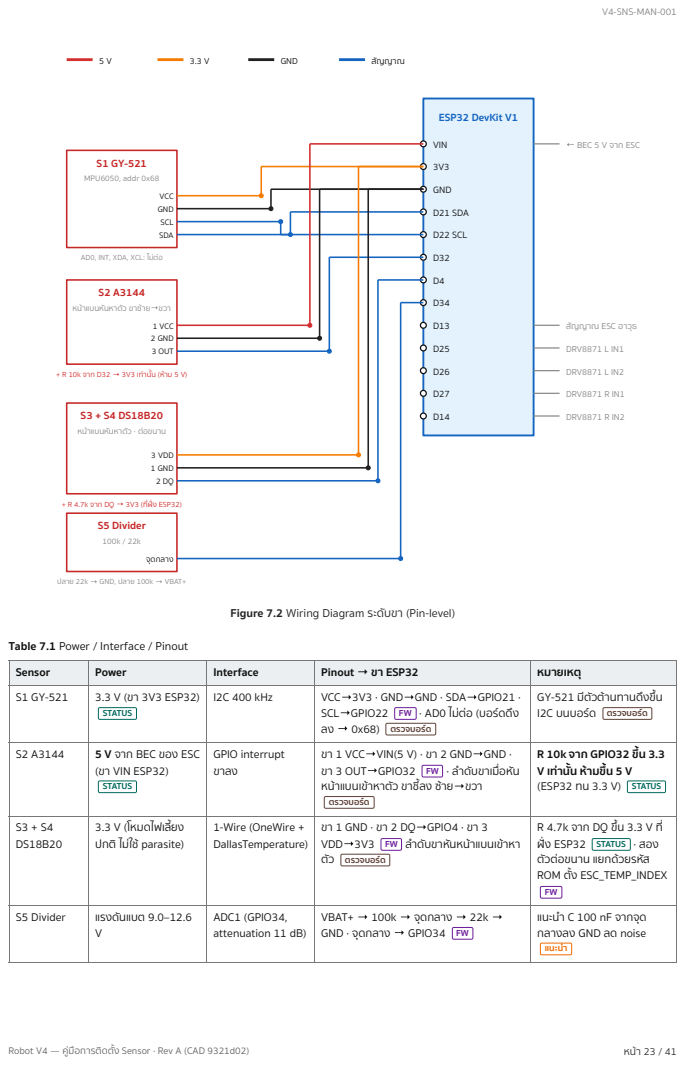
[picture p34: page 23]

AD0, INT, XDA, XCL: ไม่ต่อ
หน้าแบนหันหาตัว ขาซ้าย→ขวา

+ R 10k จาก D32 → 3V3 เท่านั้น (ห้าม 5 V)

หน้าแบนหันหาตัว · ต่อขนาน

ปลาย 22k → GND, ปลาย 100k → VBAT+

Figure 7.2 Wiring Diagram ระดับขา (Pin-level)

Table 7.1 Power / Interface / Pinout

Sensor | Power | Interface | Pinout → ขา ESP32 | หมายเหตุ
S1 GY-521 | 3.3 V (ขา 3V3 ESP32) STATUS | I2C 400 kHz | VCC→3V3 · GND→GND · SDA→GPIO21 · SCL→GPIO22 FW · AD0 ไม่ต่อ (บอร์ดดึง ลง → 0x68) ตรวจบอร์ด | GY-521 มีตัวต้านทานดึงขึ้น I2C บนบอร์ด ตรวจบอร์ด

S2 A3144 | 5 V จาก BEC ของ ESC (ขา VIN ESP32) STATUS | GPIO interrupt ขาลง | ขา 1 VCC→VIN(5 V) · ขา 2 GND→GND · ขา 3 OUT→GPIO32 FW · ลำ ดับขาเมื่อหัน หน้าแบนเข้าหาตัว ขาชี้ลง ซ้าย→ขวา ตรวจบอร์ด | R 10k จาก GPIO32 ขึ้น 3.3 V เท่านั้น ห้ามขึ้น 5 V (ESP32 ทน 3.3 V) STATUS

S3 + S4 DS18B20 | 3.3 V (โหมดไฟเลี้ยง ปกติ ไม่ใช้ parasite) | 1-Wire (OneWire + DallasTemperature) | ขา 1 GND · ขา 2 DQ→GPIO4 · ขา 3 VDD→3V3 FW ลำ ดับขาหันหน้าแบนเข้าหา ตัว ตรวจบอร์ด | R 4.7k จาก DQ ขึ้น 3.3 V ที่ ฝั่ง ESP32 STATUS · สอง ตัวต่อขนาน แยกด้วยรหัส ROM ตั้ง ESC_TEMP_INDEX FW

S5 Divider | แรงดันแบต 9.0–12.6 V | ADC1 (GPIO34, attenuation 11 dB) | VBAT+ → 100k → จุดกลาง → 22k → GND · จุดกลาง → GPIO34 FW | แนะนำ C 100 nF จากจุด กลางลง GND ลด noise แนะนำ

Robot V4 — คู่มือการติดตั้ง Sensor · Rev A (CAD 9321d02) | หน้า 24 / 41
Table 7.2 การใช้ขา ESP32 ทั้งหมดในเฟิร์มแวร์ | FW
ขา ESP32 | ใช้กับ | ขา ESP32 | ใช้กับ
GPIO21 | S1 SDA | GPIO13 | สัญญาณ ESC อาวุธ 50 Hz
GPIO22 | S1 SCL | GPIO25 / 26 | DRV8871 ซ้าย IN1 / IN2
GPIO32 | S2 OUT | GPIO27 / 14 | DRV8871 ขวา IN1 / IN2
GPIO4 | S3+S4 DQ | VIN | 5 V จาก BEC ESC (+ S2 VCC)
GPIO34 | S5 จุดกลาง | 3V3 / GND | S1, S3, S4, ตัวต้านทานดึงขึ้น / กราวด์ร่วม

## @@H7.1@@7.1 สายและขั้วต่อ

Table 7.3 สายและขั้วต่อ
รายการ | ข้อกำ หนด
สายสัญญาณ | สายซิลิโคน 26–28 AWG แกนฝอย (ทนงอและสั่น) แนะนำ
สีสาย | แดง = 5 V · ส้ม = 3.3 V · ดำ = GND · น้ำ เงิน/เหลือง/เขียว = สัญญาณ แนะนำ บันทึกสีจริง:
ขั้วต่อ | บัดกรีตรงที่ขา header ของ ESP32 + ท่อหด แนะนำ ไม่ใช้ Dupont หัวเสียบ (หลุดเมื่อโดนชน) · ถ้าต้องถอด ได้ ใช้ JST-XH 2.54 มม. แล้วหยอดกาวร้อนกันหลุด
ความยาวตามเส้นทางใน §8 (ยังไม่ เผื่อ) | S1 ≈ 73 · S2 ≈ 73 · S3 ≈ 47 (ESP32→ESC) · S4 ≈ +38 (ESC→มอเตอร์) · S5 ≈ 26 แนะนำ → ตัดเผื่อ +40 มม. ทุกเส้น
ท่อหด | หุ้มทุกจุดบัดกรีและขา sensor แยกเส้น แล้วหุ้มรวมอีกชั้น

# @@H8@@8 Cable Routing

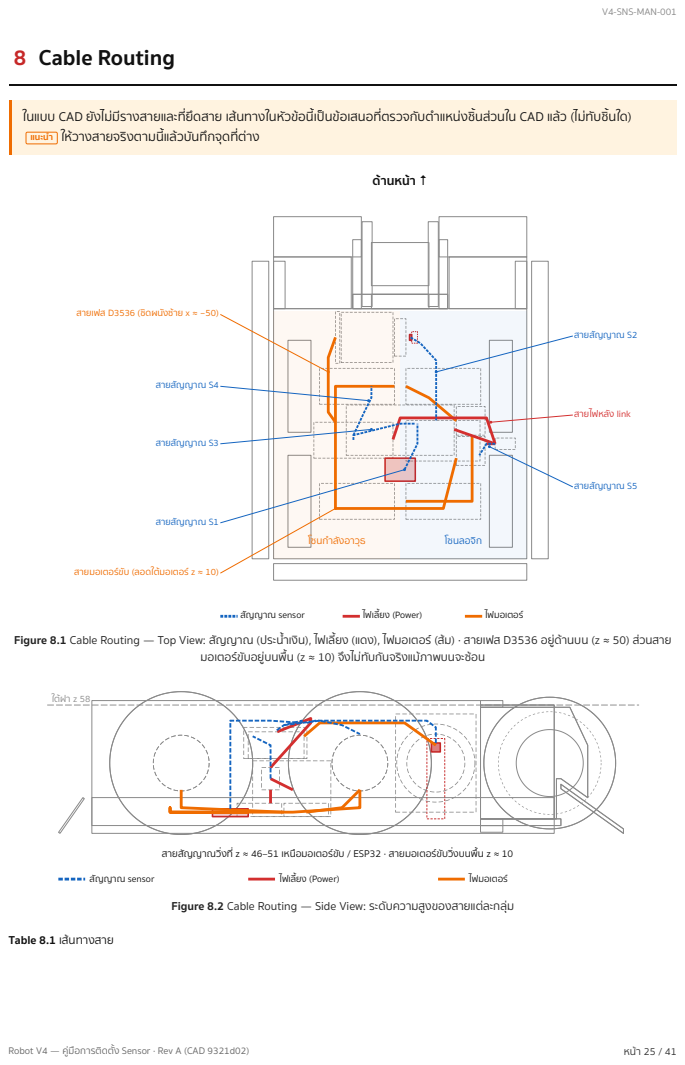
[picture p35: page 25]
Robot V4 — คู่มือการติดตั้ง Sensor · Rev A (CAD 9321d02); แนะนำ; ให้วางสายจริงตามนี้แล้วบันทึกจุดที่ต่าง; โซนกำ ลังอาวุธ; โซนลอจิก; สายสัญญาณ S2; สายสัญญาณ S1; สายสัญญาณ S3; สายสัญญาณ S4; สายสัญญาณ S5; สายไฟหลัง link; ด้านหน้า ↑; สัญญาณ sensor; ไฟเลี้ยง (Power); ไฟมอเตอร์

ในแบบ CAD ยังไม่มีรางสายและที่ยึดสาย เส้นทางในหัวข้อนี้เป็นข้อเสนอที่ตรวจกับตำ แหน่งชิ้นส่วนใน CAD แล้ว (ไม่ทับชิ้นใด)

สายเฟส D3536 (ชิดผนังซ้าย x ≈ −50)

สายมอเตอร์ขับ (ลอดใต้มอเตอร์ z ≈ 10)

Figure 8.1 Cable Routing — Top View: สัญญาณ (ประน้ำ เงิน), ไฟเลี้ยง (แดง), ไฟมอเตอร์ (ส้ม) · สายเฟส D3536 อยู่ด้านบน (z ≈ 50) ส่วนสาย

มอเตอร์ขับอยู่บนพื้น (z ≈ 10) จึงไม่ทับกันจริงแม้ภาพบนจะซ้อน

สายสัญญาณวิ่งที่ z ≈ 46–51 เหนือมอเตอร์ขับ / ESP32 · สายมอเตอร์ขับวิ่งบนพื้น z ≈ 10

Figure 8.2 Cable Routing — Side View: ระดับความสูงของสายแต่ละกลุ่ม

Table 8.1 เส้นทางสาย

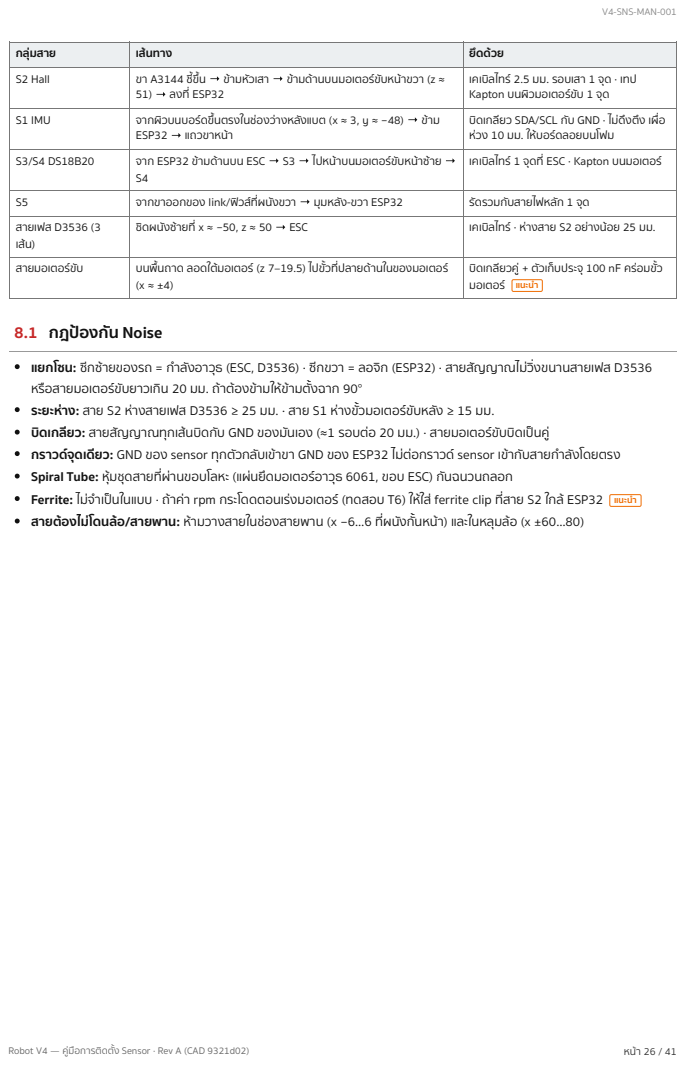
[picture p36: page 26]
Robot V4 — คู่มือการติดตั้ง Sensor · Rev A (CAD 9321d02)

กลุ่มสาย | เส้นทาง | ยึดด้วย
S2 Hall | ขา A3144 ชี้ขึ้น → ข้ามหัวเสา → ข้ามด้านบนมอเตอร์ขับหน้าขวา (z ≈ 51) → ลงที่ ESP32 | เคเบิลไทร์ 2.5 มม. รอบเสา 1 จุด · เทป Kapton บนผิวมอเตอร์ขับ 1 จุด

S1 IMU | จากผิวบนบอร์ดขึ้นตรงในช่องว่างหลังแบต (x ≈ 3, y ≈ −48) → ข้าม ESP32 → แถวขาหน้า | บิดเกลียว SDA/SCL กับ GND · ไม่ดึงตึง เผื่อ ห่วง 10 มม. ให้บอร์ดลอยบนโฟม

S3/S4 DS18B20 | จาก ESP32 ข้ามด้านบน ESC → S3 → ไปหน้าบนมอเตอร์ขับหน้าซ้าย → S4 | เคเบิลไทร์ 1 จุดที่ ESC · Kapton บนมอเตอร์

S5 | จากขาออกของ link/ฟิวส์ที่ผนังขวา → มุมหลัง-ขวา ESP32 | รัดรวมกับสายไฟหลัก 1 จุด
สายเฟส D3536 (3 เส้น) | ชิดผนังซ้ายที่ x ≈ −50, z ≈ 50 → ESC | เคเบิลไทร์ · ห่างสาย S2 อย่างน้อย 25 มม.

สายมอเตอร์ขับ | บนพื้นถาด ลอดใต้มอเตอร์ (z 7–19.5) ไปขั้วที่ปลายด้านในของมอเตอร์ (x ≈ ±4) | บิดเกลียวคู่ + ตัวเก็บประจุ 100 nF คร่อมขั้ว มอเตอร์ แนะนำ

@@H8.1@@8.1 กฎป้องกัน Noise

แยกโซน: ซีกซ้ายของรถ = กำ ลังอาวุธ (ESC, D3536) · ซีกขวา = ลอจิก (ESP32) · สายสัญญาณไม่วิ่งขนานสายเฟส D3536
หรือสายมอเตอร์ขับยาวเกิน 20 มม. ถ้าต้องข้ามให้ข้ามตั้งฉาก 90°
ระยะห่าง: สาย S2 ห่างสายเฟส D3536 ≥ 25 มม. · สาย S1 ห่างขั้วมอเตอร์ขับหลัง ≥ 15 มม.
บิดเกลียว: สายสัญญาณทุกเส้นบิดกับ GND ของมันเอง (≈1 รอบต่อ 20 มม.) · สายมอเตอร์ขับบิดเป็นคู่
กราวด์จุดเดียว: GND ของ sensor ทุกตัวกลับเข้าขา GND ของ ESP32 ไม่ต่อกราวด์ sensor เข้ากับสายกำ ลังโดยตรง
Spiral Tube: หุ้มชุดสายที่ผ่านขอบโลหะ (แผ่นยึดมอเตอร์อาวุธ 6061, ขอบ ESC) กันฉนวนถลอก
Ferrite: ไม่จำ เป็นในแบบ · ถ้าค่า rpm กระโดดตอนเร่งมอเตอร์ (ทดสอบ T6) ให้ใส่ ferrite clip ที่สาย S2 ใกล้ ESP32 แนะนำ
สายต้องไม่โดนล้อ/สายพาน: ห้ามวางสายในช่องสายพาน (x −6…6 ที่ผนังกั้นหน้า) และในหลุมล้อ (x ±60…80)

Robot V4 — คู่มือการติดตั้ง Sensor · Rev A (CAD 9321d02) | หน้า 27 / 41

# @@H9@@9 Installation Procedure

เครื่องมือ: ไม้บรรทัดเหล็ก/เวอร์เนีย, ปากกาเขียนชิ้นงาน, สว่านมือ + ดอก Ø1.6 / Ø2.2 (ถ้าใช้สกรูเสา), หัวแร้ง + ตะกั่ว, ท่อหด, มัลติ มิเตอร์, ดอกสว่าน Ø2.5 (ใช้เป็นฟีลเลอร์), โน้ตบุ๊ก + สาย USB · ก่อนเริ่ม: ถอด removable link, ถอดโรเตอร์หรือเสียบหมุดล็อกใบ, ถอดฝา

## STEP 1 — กำ หนดจุดติดตั้ง

ทำ เครื่องหมายกากบาทบนพื้นถาด: S1 ที่กึ่งกลางบอร์ด, S2 ที่กึ่งกลาง เสา · S3/S4 กำ หนดบนชิ้นจริงหลังเห็น ESC และมอเตอร์ (§3.3, §3.4)

S1

### S2 (เสา)

ทำ เครื่องหมายบนพื้นถาด (มองจากบน)

## STEP 2 — วัดตำ แหน่งจากผิวอ้างอิง

S1: 62 จาก R1 (ผนังหลังนอก) บนเส้น CL · S2 (กลางเสา x_CAD 10, y_CAD 44): 154 จาก R1, 78 จาก R2 (ผนังขวานอก) · วัดซ้ำ จาก R3 เพื่อตรวจ (S2: 98)

62

154

7788 ((ถึถึถึงถึงกกลลาางงเเสสาา))

วัดจากผนังหลัง/ผนังขวาด้านนอก + เส้นกึ่งกลาง

Robot V4 — คู่มือการติดตั้ง Sensor · Rev A (CAD 9321d02) | หน้า 28 / 41

## STEP 3 — เจาะรู (เฉพาะทางเลือกสกรู S2)

แบบ CAD ไม่มีรูสำ หรับ sensor CAD · ถ้าเลือกยึดเสาด้วยสกรู: เจาะพื้น
ถาด Ø2.2 ที่จุด S2 และรูนำ | Ø1.6 ลึก 6 ที่ก้นเสา แนะนำ | · ไม่เจาะรู M3
ใดๆ สำ หรับ sensor

สกรูเกลียวปล่อย M2×10 จากใต้ท้อง

รูนำ Ø1.6 ลึก 6

รูพื้นถาด Ø2.2

ทางเลือกแนะนำ (ไม่อยู่ในแบบ)

## STEP 4 — ติด Bracket (เสา S2)

### ต้องประกอบมอเตอร์อาวุธและรอกเข้าที่ก่อน (ใช้หน้ารอกเป็นผิวอ้างอิง)

- วางเสาให้หน้าเสาด้านรอกห่างหน้ารอก 4.0 มม. (= 2.5 ระยะห่าง + 1.5 ความหนา TO-92) และขอบหน้าเสาห่าง R4 16 มม. · ติดกาว/ขันสกรู แล้ว

วัดซ้ำ

44..00 ((หหน้น้น้าน้ารรออกก→→เเสสาา))

8

ติดเสาให้หน้าเสาห่างหน้ารอก 4.0 มม.

## STEP 5 — ติด Sensor

S1: แปะโฟม 1 มม. แล้วกด GY-521 ลง ด้านชิปขึ้น · S2: ติด A3144 ที่ หน้าเสา หน้าแบนหันหารอก ขาชี้ขึ้น ขอบบนตัว sensor ต่ำ กว่าหัวเสา 2 มม. · S3/S4: ติดตาม Figure 6.3

S1 บนโฟม

S2 ขาชี้ขึ้น

## STEP 6 — ตั้งมุมและระยะ

## STEP 7 — เดินสาย

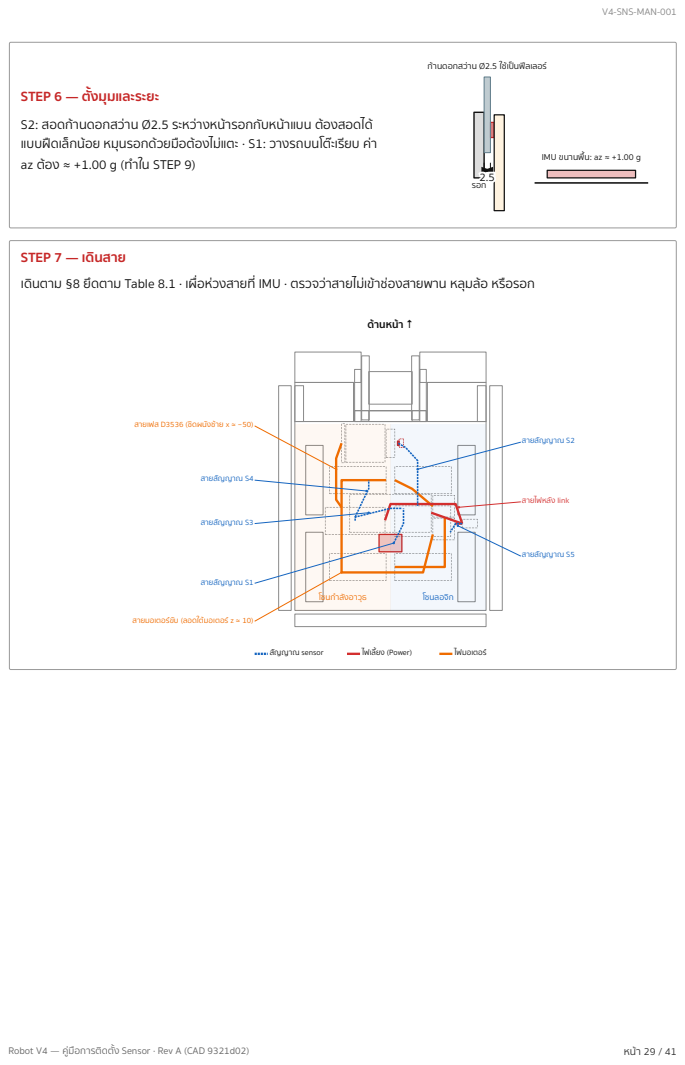
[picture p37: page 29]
Robot V4 — คู่มือการติดตั้ง Sensor · Rev A (CAD 9321d02); รอก; โซนกำ ลังอาวุธ; โซนลอจิก; สายสัญญาณ S2; สายสัญญาณ S1; สายสัญญาณ S3; สายสัญญาณ S4; สายสัญญาณ S5; สายไฟหลัง link; ด้านหน้า ↑; สัญญาณ sensor; ไฟเลี้ยง (Power); ไฟมอเตอร์

ก้านดอกสว่าน Ø2.5 ใช้เป็นฟีลเลอร์

S2: สอดก้านดอกสว่าน Ø2.5 ระหว่างหน้ารอกกับหน้าแบน ต้องสอดได้
แบบฝืดเล็กน้อย หมุนรอกด้วยมือต้องไม่แตะ · S1: วางรถบนโต๊ะเรียบ ค่า
az ต้อง ≈ +1.00 g (ทำ ใน STEP 9)

IMU ขนานพื้น: az ≈ +1.00 g

เดินตาม §8 ยึดตาม Table 8.1 · เผื่อห่วงสายที่ IMU · ตรวจว่าสายไม่เข้าช่องสายพาน หลุมล้อ หรือรอก

สายเฟส D3536 (ชิดผนังซ้าย x ≈ −50)

สายมอเตอร์ขับ (ลอดใต้มอเตอร์ z ≈ 10)

## STEP 8 — เชื่อมต่อ Controller

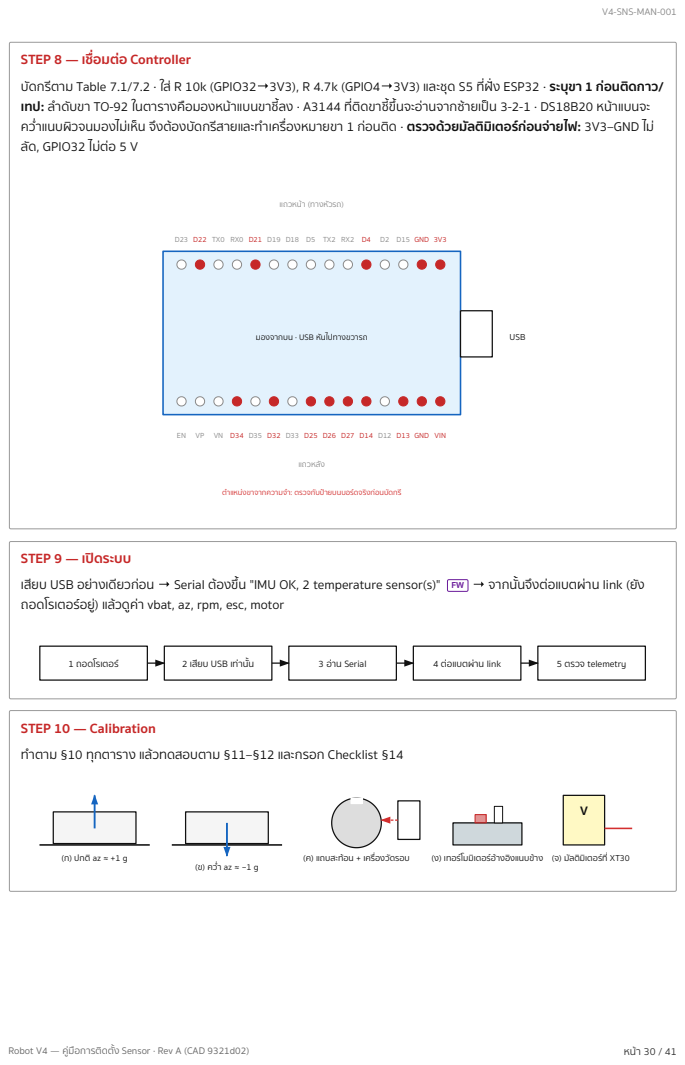
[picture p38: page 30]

บัดกรีตาม Table 7.1/7.2 · ใส่ R 10k (GPIO32→3V3), R 4.7k (GPIO4→3V3) และชุด S5 ที่ฝั่ง ESP32 · ระบุขา 1 ก่อนติดกาว/
เทป: ลำ ดับขา TO-92 ในตารางคือมองหน้าแบนขาชี้ลง · A3144 ที่ติดขาชี้ขึ้นจะอ่านจากซ้ายเป็น 3-2-1 · DS18B20 หน้าแบนจะ
คว่ำ แนบผิวจนมองไม่เห็น จึงต้องบัดกรีสายและทำ เครื่องหมายขา 1 ก่อนติด · ตรวจด้วยมัลติมิเตอร์ก่อนจ่ายไฟ: 3V3–GND ไม่
ลัด, GPIO32 ไม่ต่อ 5 V

EN VP VN D34 D35 D32 D33 D25 D26 D27 D14 D12 D13 GND VIN

ตำ แหน่งขาจากความจำ : ตรวจกับป้ายบนบอร์ดจริงก่อนบัดกรี

STEP 9 — เปิดระบบ
เสียบ USB อย่างเดียวก่อน → Serial ต้องขึ้น "IMU OK, 2 temperature sensor(s)" FW → จากนั้นจึงต่อแบตผ่าน link (ยัง
ถอดโรเตอร์อยู่) แล้วดูค่า vbat, az, rpm, esc, motor

STEP 10 — Calibration
ทำ ตาม §10 ทุกตาราง แล้วทดสอบตาม §11–§12 และกรอก Checklist §14

# @@H10@@10 Calibration

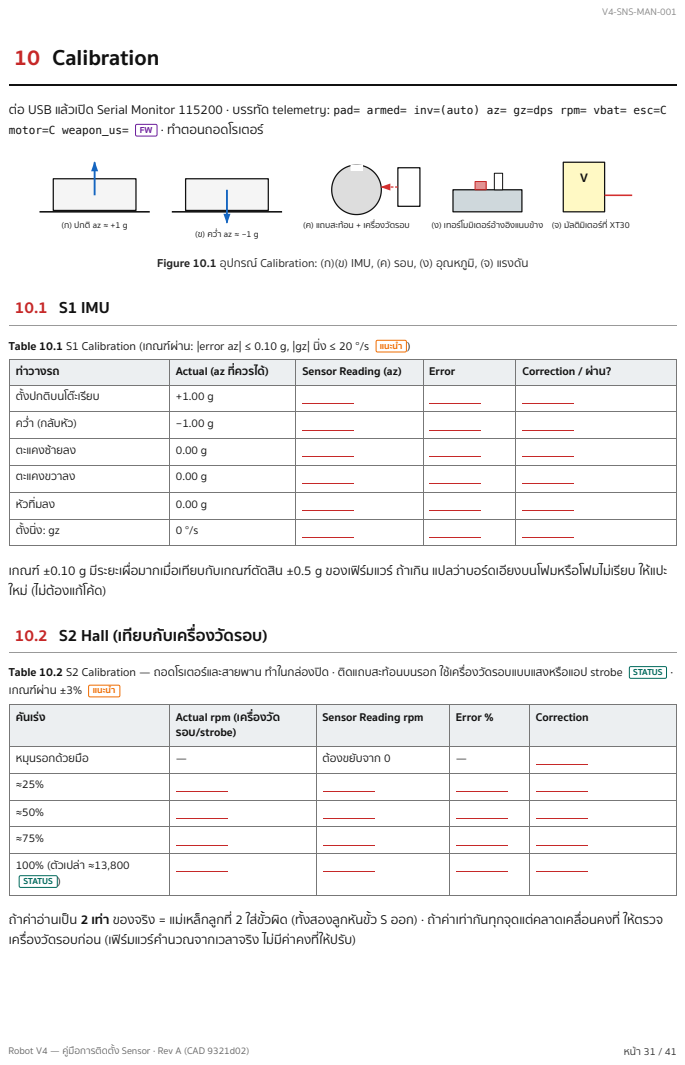
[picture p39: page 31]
Robot V4 — คู่มือการติดตั้ง Sensor · Rev A (CAD 9321d02); (ก) ปกติ az ≈ +1 g; (ค) แถบสะท้อน + เครื่องวัดรอบ; (ง) เทอร์โมมิเตอร์อ้างอิงแนบข้าง; (จ) มัลติมิเตอร์ที่ XT30; @@H10.1@@10.1 S1 IMU; Table 10.1 S1 Calibration (เกณฑ์ผ่าน: |error az| ≤ 0.10 g, |gz| นิ่ง ≤ 20 °/s แนะนำ

ต่อ USB แล้วเปิด Serial Monitor 115200 · บรรทัด telemetry: pad= armed= inv=(auto) az= gz=dps rpm= vbat= esc=C
motor=C weapon_us= FW · ทำ ตอนถอดโรเตอร์

Figure 10.1 อุปกรณ์Calibration: (ก)(ข) IMU, (ค) รอบ, (ง) อุณหภูมิ, (จ) แรงดัน

ท่าวางรถ | Actual (az ที่ควรได้) | Sensor Reading (az) | Error | Correction / ผ่าน?
ตั้งปกติบนโต๊ะเรียบ | +1.00 g
คว่ำ (กลับหัว) | −1.00 g
ตะแคงซ้ายลง | 0.00 g
ตะแคงขวาลง | 0.00 g
หัวทิ่มลง | 0.00 g
ตั้งนิ่ง: gz | 0 °/s

เกณฑ์ ±0.10 g มีระยะเผื่อมากเมื่อเทียบกับเกณฑ์ตัดสิน ±0.5 g ของเฟิร์มแวร์ ถ้าเกิน แปลว่าบอร์ดเอียงบนโฟมหรือโฟมไม่เรียบ ให้แปะ
ใหม่ (ไม่ต้องแก้โค้ด)
@@H10.2@@10.2 S2 Hall (เทียบกับเครื่องวัดรอบ)

Table 10.2 S2 Calibration — ถอดโรเตอร์และสายพาน ทำ ในกล่องปิด · ติดแถบสะท้อนบนรอก ใช้เครื่องวัดรอบแบบแสงหรือแอป strobe STATUS ·
เกณฑ์ผ่าน ±3% แนะนำ

คันเร่ง | Actual rpm (เครื่องวัด รอบ/strobe) | Sensor Reading rpm | Error % | Correction

หมุนรอกด้วยมือ | — | ต้องขยับจาก 0 | —
≈25%
≈50%
≈75%
100% (ตัวเปล่า ≈13,800 STATUS )

ถ้าค่าอ่านเป็น 2 เท่า ของจริง = แม่เหล็กลูกที่ 2 ใส่ขั้วผิด (ทั้งสองลูกหันขั้ว S ออก) · ถ้าค่าเท่ากันทุกจุดแต่คลาดเคลื่อนคงที่ ให้ตรวจ
เครื่องวัดรอบก่อน (เฟิร์มแวร์คำนวณจากเวลาจริง ไม่มีค่าคงที่ให้ปรับ)

Robot V4 — คู่มือการติดตั้ง Sensor · Rev A (CAD 9321d02) | หน้า 32 / 41

## @@H10.3@@10.3 S3/S4 DS18B20

Table 10.3 S3/S4 Calibration — เกณฑ์ผ่าน ±2 °C แนะนำ
จุดทดสอบ | Actual (เทอร์โมมิเตอร์ อ้างอิง) | S3 esc | S4 motor | Error | Correction

อุณหภูมิห้อง
อุ่นด้วยไดร์เป่าผม ≈50 °C
เอานิ้วอุ่นทีละตัว | — | ค่าขึ้น? | ค่าขึ้น? | — | ESC_TEMP_INDEX =

DS18B20 ถูกเรียงตามรหัส ROM ไม่ใช่ตามการต่อสาย ถ้าอุ่นตัวที่ ESC แล้วค่า motor ขึ้น ให้เปลี่ยน ESC_TEMP_INDEX จาก 0 เป็น 1 แล้วอัปโหลดใหม่ FW

## @@H10.4@@10.4 S5 แรงดันแบต

Table 10.4 S5 Calibration — เกณฑ์ผ่าน ±0.10 V แนะนำ
จุดทดสอบ | Actual (มัลติมิเตอร์ที่ XT30) | Sensor Reading vbat | Error | Correction factor = Actual / Reading

แบตเต็ม ≈12.6 V
แบตกลาง ≈11.1 V
แบตใกล้หมด / แหล่งจ่าย 10.5 V

ถ้าไม่ผ่าน: ค่าใหม่ของ VBAT_DIVIDER = 5.545 × (ค่าเฉลี่ย Actual / Reading) (ค่าเดิม (100+22)/22 = 5.545) FW แล้วอัปโหลด

และวัดซ้ำ

# @@H11@@11 Sensor Test

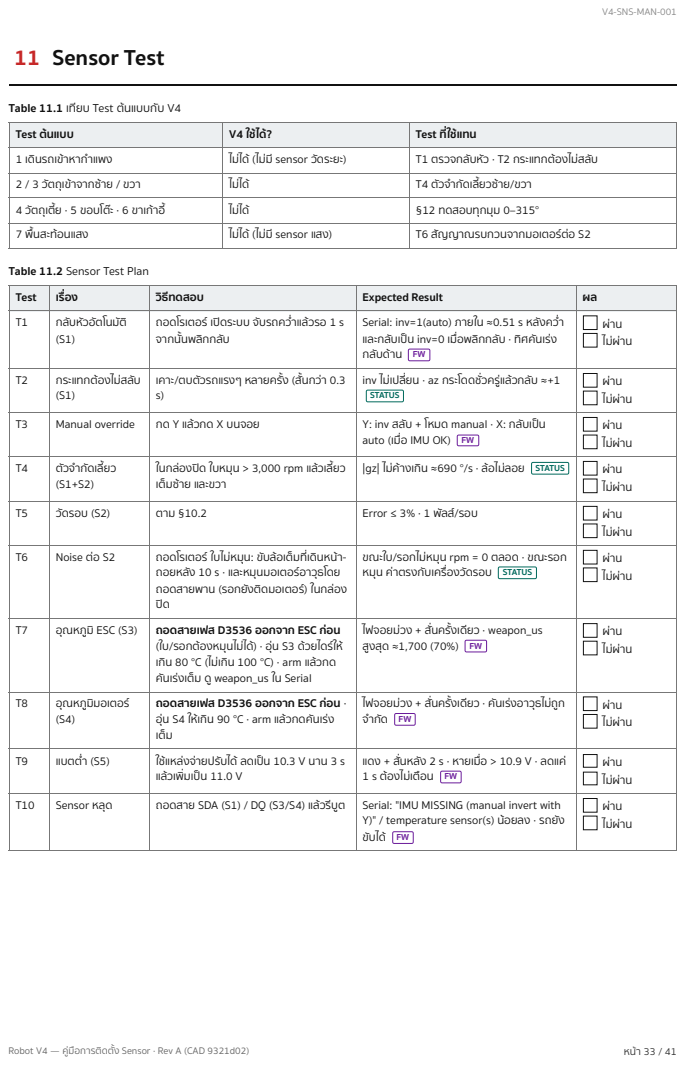
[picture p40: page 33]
Robot V4 — คู่มือการติดตั้ง Sensor · Rev A (CAD 9321d02)

Table 11.1 เทียบ Test ต้นแบบกับ V4

Test ต้นแบบ | V4 ใช้ได้? | Test ที่ใช้แทน
1 เดินรถเข้าหากำ แพง | ไม่ได้ (ไม่มี sensor วัดระยะ) | T1 ตรวจกลับหัว · T2 กระแทกต้องไม่สลับ
2 / 3 วัตถุเข้าจากซ้าย / ขวา | ไม่ได้ | T4 ตัวจำ กัดเลี้ยวซ้าย/ขวา
4 วัตถุเตี้ย · 5 ขอบโต๊ะ · 6 ขาเก้าอี้ | ไม่ได้ | §12 ทดสอบทุกมุม 0–315°
7 พื้นสะท้อนแสง | ไม่ได้ (ไม่มี sensor แสง) | T6 สัญญาณรบกวนจากมอเตอร์ต่อ S2

Table 11.2 Sensor Test Plan

Test | เรื่อง | วิธีทดสอบ | Expected Result | ผล

T1 | กลับหัวอัตโนมัติ (S1) | ถอดโรเตอร์ เปิดระบบ จับรถคว่ำ แล้วรอ 1 s จากนั้นพลิกกลับ | Serial: inv=1(auto) ภายใน ≈0.51 s หลังคว่ำ และกลับเป็น inv=0 เมื่อพลิกกลับ · ทิศคันเร่ง กลับด้าน FW | ผ่าน ไม่ผ่าน

T2 | กระแทกต้องไม่สลับ (S1) | เคาะ/ตบตัวรถแรงๆ หลายครั้ง (สั้นกว่า 0.3 s) | inv ไม่เปลี่ยน · az กระโดดชั่วครู่แล้วกลับ ≈+1 STATUS | ผ่าน ไม่ผ่าน

T3 | Manual override | กด Y แล้วกด X บนจอย | Y: inv สลับ + โหมด manual · X: กลับเป็น auto (เมื่อ IMU OK) FW | ผ่าน ไม่ผ่าน

T4 | ตัวจำ กัดเลี้ยว (S1+S2) | ในกล่องปิด ใบหมุน > 3,000 rpm แล้วเลี้ยว เต็มซ้าย และขวา | |gz| ไม่ค้างเกิน ≈690 °/s · ล้อไม่ลอย STATUS | ผ่าน ไม่ผ่าน

T5 | วัดรอบ (S2) | ตาม §10.2 | Error ≤ 3% · 1 พัลส์/รอบ | ผ่าน ไม่ผ่าน

T6 | Noise ต่อ S2 | ถอดโรเตอร์ ใบไม่หมุน: ขับล้อเต็มที่เดินหน้า-ถอยหลัง 10 s · และหมุนมอเตอร์อาวุธโดย ถอดสายพาน (รอกยังติดมอเตอร์) ในกล่อง ปิด | ขณะใบ/รอกไม่หมุน rpm = 0 ตลอด · ขณะรอก หมุน ค่าตรงกับเครื่องวัดรอบ STATUS | ผ่าน ไม่ผ่าน

T7 | อุณหภูมิ ESC (S3) | ถอดสายเฟส D3536 ออกจาก ESC ก่อน (ใบ/รอกต้องหมุนไม่ได้) · อุ่น S3 ด้วยไดร์ให้ เกิน 80 °C (ไม่เกิน 100 °C) · arm แล้วกด คันเร่งเต็ม ดู weapon_us ใน Serial | ไฟจอยม่วง + สั่นครั้งเดียว · weapon_us สูงสุด ≈1,700 (70%) FW | ผ่าน ไม่ผ่าน

T8 | อุณหภูมิมอเตอร์ (S4) | ถอดสายเฟส D3536 ออกจาก ESC ก่อน · อุ่น S4 ให้เกิน 90 °C · arm แล้วกดคันเร่ง เต็ม | ไฟจอยม่วง + สั่นครั้งเดียว · คันเร่งอาวุธไม่ถูก จำ กัด FW | ผ่าน ไม่ผ่าน

T9 | แบตต่ำ (S5) | ใช้แหล่งจ่ายปรับได้ ลดเป็น 10.3 V นาน 3 s แล้วเพิ่มเป็น 11.0 V | แดง + สั่นหลัง 2 s · หายเมื่อ > 10.9 V · ลดแค่ 1 s ต้องไม่เตือน FW | ผ่าน ไม่ผ่าน

T10 | Sensor หลุด | ถอดสาย SDA (S1) / DQ (S3/S4) แล้วรีบูต | Serial: "IMU MISSING (manual invert with Y)" / temperature sensor(s) น้อยลง · รถยัง ขับได้ FW | ผ่าน ไม่ผ่าน

Robot V4 — คู่มือการติดตั้ง Sensor · Rev A (CAD 9321d02) | หน้า 34 / 41

# @@H12@@12 Blind Spot Test (ทดสอบตรวจกลับหัวทุกมุม)

ต้นแบบให้วางวัตถุรอบรถที่ 0–315° ระยะ 10–50 cm · V4 ไม่มี sensor วัดระยะ จึงใช้ตารางเดียวกันกับมุมเอียงของตัวรถ (0– 315°) และเวลาค้าง (0.2–1.5 s) แทนระยะ เพื่อหา "มุมบอด" ของการตรวจกลับหัว แนะนำ

0°

45°

90°

135°

180°

225°

270°

315°

เขียว: ปกติ (0–60°, 300–360°)
เทา: คงสถานะเดิม (60–120°, 240–300°) แดง: กลับหัว (120–240°)
az = cos(มุมเอียง) · เกณฑ์ ±0.5 g เปลี่ยนสถานะเมื่อค้าง > 0.3 s หลังผ่านเกณฑ์ พลิก 180° ทันที → สลับประมาณ 0.51 s

มุมเอียงรอบแกน Roll หรือ Pitch (ผลเหมือนกัน)
Figure 12.1 แผนที่สถานะตามมุมเอียง: az = cos θ เทียบเกณฑ์ ±0.5 g FW

วิธีทำ : ถอดโรเตอร์ เริ่มจากรถตั้งปกติ (inv=0) จับรถหมุนรอบแกน Roll (ตะแคง) ไปที่มุมที่กำ หนดเร็วๆ ค้างตามเวลา แล้วอ่าน inv ใน Serial · ทำ ซ้ำ รอบแกน Pitch (หัวทิ่ม) · ค่าคาดหมายคำนวณจากตัวกรองในเฟิร์มแวร์ (τ ≈ 0.15 s, ค้าง 0.3 s) FW ตัวเลขในวงเล็บ คือเวลาที่คาดว่าจะสลับ
ผลที่ยอมรับได้: ทุกช่องตรงกับค่าคาด · มุม 90° และ 270° ต้องคงสถานะเดิม (ไม่สลับไปมาเมื่อรถตะแคงพิงผนัง) · ถ้าช่อง 0.2/0.4 s สลับ = ตัวกรองไม่ทำ งาน ห้ามใช้แข่ง

Robot V4 — คู่มือการติดตั้ง Sensor · Rev A (CAD 9321d02) | หน้า 35 / 41

Table 12.1 ตารางผล Blind Spot Test (กรอกค่า inv ที่อ่านได้: 0 = ปกติ, 1 = กลับหัว)
มุม | az | โซน | ค้าง 0.2 s | ค้าง 0.4 s | ค้าง 0.8 s | ค้าง 1.5 s
0° | +1.00 | ปกติ | คาด 0 · Roll Pitch | คาด 0 · Roll Pitch | คาด 0 · Roll Pitch | คาด 0 · Roll Pitch
45° | +0.71 | ปกติ | คาด 0 · Roll Pitch | คาด 0 · Roll Pitch | คาด 0 · Roll Pitch | คาด 0 · Roll Pitch
90° | +0.00 | คงสถานะ | คาด 0 · Roll Pitch | คาด 0 · Roll Pitch | คาด 0 · Roll Pitch | คาด 0 · Roll Pitch
135° | -0.71 | กลับหัว (0.62 s) | คาด 0 · Roll Pitch | คาด 0 · Roll Pitch | คาด 1 · Roll Pitch | คาด 1 · Roll Pitch
180° | -1.00 | กลับหัว (0.51 s) | คาด 0 · Roll Pitch | คาด 0 · Roll Pitch | คาด 1 · Roll Pitch | คาด 1 · Roll Pitch
225° | -0.71 | กลับหัว (0.62 s) | คาด 0 · Roll Pitch | คาด 0 · Roll Pitch | คาด 1 · Roll Pitch | คาด 1 · Roll Pitch
270° | +0.00 | คงสถานะ | คาด 0 · Roll Pitch | คาด 0 · Roll Pitch | คาด 0 · Roll Pitch | คาด 0 · Roll Pitch
315° | +0.71 | ปกติ | คาด 0 · Roll Pitch | คาด 0 · Roll Pitch | คาด 0 · Roll Pitch | คาด 0 · Roll Pitch

Robot V4 — คู่มือการติดตั้ง Sensor · Rev A (CAD 9321d02) | หน้า 36 / 41

# @@H13@@13 Collision Safety

ต้นแบบกำ หนดโซนหยุดตามระยะ (0–10 / 10–30 / 30–100 cm) ซึ่งต้องใช้ sensor วัดระยะ · V4 เป็นหุ่นแข่งที่ตั้งใจชน จึงไม่มี การหยุดอัตโนมัติตามระยะ Emergency Stop ของ V4 คือ (1) ปุ่ม B ปลดอาวุธทันที (2) failsafe เมื่อไม่ได้ข้อมูลจอย > 250 ms
(3) ถอด removable link FW STATUS หัวข้อนี้จึงแสดงโซนค่าเตือนของ sensor และเขตอันตรายทางกายภาพแทน

รอบใบ (S2) < 3,000: ไม่จำ กัดเลี้ยว

0

จำ กัดเลี้ยว 690°/s

3000

≥ 10,000: เขียว พร้อมตี

10000 | 14000 rpm
ESC อาวุธ (S3) | ปกติ

20

> 80 °C: ม่วง + คันเร่งอาวุธ ≤ 70%

80 | 110 °C
มอเตอร์ขับ (S4) | ปกติ

20

> 90 °C: ม่วง + เตือน

90 | 110 °C
แบต (S5) | < 10.5 V นาน 2 s: แดง

9.5

hysteresis

10.5

> 10.9 V: หายเตือน

10.9 | 12.8 V
Figure 13.1 Safety Zones ของค่าที่ sensor วัด และการตอบสนองของเฟิร์มแวร์ | FW

Table 13.1 สถานะบนจอย (จอยเลียนแบบบางรุ่นอาจไม่มีไฟหรือไม่สั่น)
สีไฟจอย | ความหมาย STATUS
น้ำ เงิน | ปลอดภัย (ยังไม่ arm)
เหลือง | arm แล้ว (L1+R1 ค้าง 1 s)
เขียว | ใบหมุน ≥ 10,000 rpm พร้อมตี
ม่วง | ESC > 80 °C หรือมอเตอร์ขับ > 90 °C
แดง | แบต < 10.5 V นานเกิน 2 s

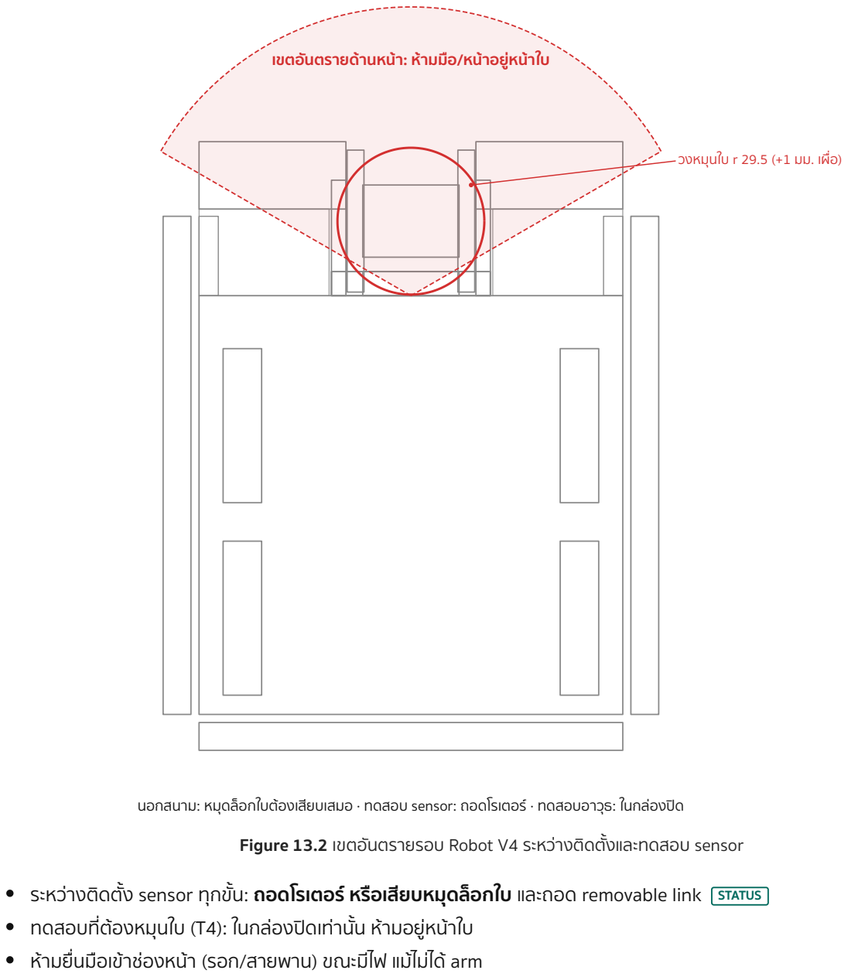
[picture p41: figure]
เขตอันตรายด้านหน้า: ห้ามมือ/หน้าอยู่หน้าใบ; วงหมุนใบ r 29.5 (+1 มม. เผื่อ); ทดสอบที่ต้องหมุนใบ (T4): ในกล่องปิดเท่านั้น ห้ามอยู่หน้าใบ ห้ามยื่นมือเข้าช่องหน้า (รอก/สายพาน) ขณะมีไฟ แม้ไม่ได้ arm

Robot V4 — คู่มือการติดตั้ง Sensor · Rev A (CAD 9321d02) | หน้า 37 / 41

นอกสนาม: หมุดล็อกใบต้องเสียบเสมอ · ทดสอบ sensor: ถอดโรเตอร์ · ทดสอบอาวุธ: ในกล่องปิด
Figure 13.2 เขตอันตรายรอบ Robot V4 ระหว่างติดตั้งและทดสอบ sensor ระหว่างติดตั้ง sensor ทุกขั้น: ถอดโรเตอร์ หรือเสียบหมุดล็อกใบ และถอด removable link STATUS

Robot V4 — คู่มือการติดตั้ง Sensor · Rev A (CAD 9321d02) | หน้า 38 / 41

# @@H14@@14 Installation Checklist

Table 14.1 Checklist ก่อนใช้งานจริง
หมวด | รายการตรวจ | ผู้ตรวจ
S1 | IMU แปะเต็มหน้าบนโฟม 1 มม. ด้านชิปขึ้น ขอบขนานแกนรถ ระยะ 62 จาก R1 บน CL
S1 | กดบอร์ดเบาๆ ไม่โยก ไม่สั่นค้าง · สายมีห่วงเผื่อ ไม่ดึงบอร์ด
S2 | เสา PETG ติดแน่น โยกด้วยนิ้วไม่ขยับ · ระยะหน้ารอก–หน้าแบน 2.5 มม. (ฟีลเลอร์ Ø2.5 ผ่านฝืด)
S2 | หมุนรอกด้วยมือครบรอบ ไม่แตะ sensor · แม่เหล็ก 2 ลูก ขั้ว S/N ถูก · กาวแห้งแล้ว
S3/S4 | DS18B20 แนบผิว ESC และกระป๋องมอเตอร์หน้าซ้าย (ไม่ใช่มอเตอร์อาวุธ) · Kapton ไม่ร่อน
S5 | จุดรับไฟอยู่หลัง link/ฟิวส์ · หุ้มท่อหดทั้งชุด
มุม | มุมติดตั้งตรง §3: S1 Pitch/Roll 0°, S2 หน้าแบนหันหารอก
สาย | สายไม่โดนล้อ สายพาน รอก หรือหลุมล้อ · ไม่เข้าช่องสายพาน x −6…6
สาย | สายสัญญาณห่างสายเฟส D3536 ≥ 25 มม. · ข้ามสายกำ ลังแบบตั้งฉาก
ไฟ | R 10k ของ S2 ต่อขึ้น 3.3 V (ไม่ใช่ 5 V) · A3144 เลี้ยงด้วย 5 V
ไฟ | จุดบัดกรีมีท่อหดครบ · ขั้วต่อแน่น ดึงเบาๆ ไม่หลุด
อ่านค่า | Serial ขึ้น "IMU OK, 2 temperature sensor(s)" · ค่า rpm, vbat, esc, motor มีค่า
Calibration | §10 ผ่านทุกตาราง · ตั้ง ESC_TEMP_INDEX แล้ว
Test | T1–T10 ผ่าน · ตาราง §12 ตรงค่าคาดทุกช่อง (ไม่มี blind spot สำ คัญ)
E-Stop | ปุ่ม B ปลดอาวุธทันที · ปิดจอยแล้วหยุดภายใน 0.25 s · ถอด link แล้วดับทั้งระบบ
ปิดฝา | ปิดฝาแล้วไม่กดทับสายหรือ sensor (S2 ห่างใต้ฝา 19 มม.) · ขันสกรูฝา M3 ครบ 6 ตัว
ผู้ติดตั้ง | ผู้ตรวจ | วันที่

Robot V4 — คู่มือการติดตั้ง Sensor · Rev A (CAD 9321d02) | หน้า 39 / 41

# @@H15@@15 Maintenance

V4 ไม่มีข้อมูลชั่วโมงใช้งานจริง STATUS จึงกำ หนดรอบการตรวจตามเหตุการณ์ (ก่อน/หลังแมตช์) แทนชั่วโมง แนะนำ ให้ปรับรอบ หลังสะสมข้อมูลจริง

Table 15.1 ตารางบำ รุงรักษา
รอบ | Sensor ที่ตรวจ | ตรวจอะไร / ทำ อย่างไร
ก่อนทุกแมตช์ | ทั้งหมด | เปิดระบบดู Serial หรือไฟจอย · T1 (คว่ำ รถ) · หมุนรอกด้วยมือดู rpm ขยับ · vbat ตรงมิเตอร์ ±0.1 V
หลังทุกแมตช์ / หลังโดนชน แรง | S2, S1 | ตรวจระยะ 2.5 มม. ด้วยฟีลเลอร์ (พื้น TPU ยุบ/เสาเอียง) · เก็บเศษเหล็กที่ดูดติดแม่เหล็กบน รอก · IMU ยังแปะแน่น · ตรวจแกน ลูกปืน สายพาน น็อต STATUS
หลังทุกแมตช์ | สาย | สายไม่ถลอกที่ขอบโลหะ · ท่อหดไม่หลุด · เคเบิลไทร์ไม่ขาด
จบทุกวันแข่ง | ขายึด | เสา PETG ไม่ร้าวที่ฐาน · กาว/สกรูไม่คลอน · Kapton ของ S3/S4 ไม่ร่อน (ความร้อนทำ ให้กาว เสื่อม)
จบทุกวันแข่ง | Calibration | ทำ §10.1 (IMU ท่าปกติ/คว่ำ ) และ §10.4 (vbat 1 จุด) · ถ้าเกินเกณฑ์ทำ เต็มตาราง
เมื่อเปลี่ยนชิ้นส่วน | ตามชิ้น | เปลี่ยน ESC/มอเตอร์ → ติด S3/S4 ใหม่และตรวจ ESC_TEMP_INDEX · เปลี่ยนรอก → ใส่แม่ เหล็กและตรวจขั้วใหม่ · เปลี่ยนถาด → วัดตำ แหน่งตาม §9

## @@H15.1@@15.1 การทำ ความสะอาด

ใช้ลมเป่าหรือแปรงขนนุ่มปัดฝุ่นและเศษยาง · ใช้แอลกอฮอล์ IPA เช็ดหน้าสัมผัสบัดกรีที่สกปรก ห้ามใช้น้ำ แม่เหล็กบนรอกดูดเศษเหล็กจากจานใบและพื้นสนาม: เช็ดด้วยเทปกาวแตะออก ห้ามใช้ไขควงงัดผิวแม่เหล็ก ห้ามเป่าลมแรงตรงๆ ใส่ IMU นานๆ (ทำ ให้ gyro อ่านค่าหมุนชั่วคราว)

Robot V4 — คู่มือการติดตั้ง Sensor · Rev A (CAD 9321d02) | หน้า 40 / 41

# @@H16@@16 Troubleshooting

Table 16.1 Troubleshooting
อาการ | สาเหตุที่เป็นไปได้ | วิธีแก้
Serial ขึ้น "IMU MISSING" | สาย SDA/SCL สลับหรือหลุด · ไม่มีไฟ 3.3 V · บอร์ด เสีย | วัด 3.3 V ที่ VCC · ตรวจ SDA→21, SCL→22 · ต่อใหม่ · ระหว่างนี้ใช้ปุ่ม Y สลับกลับหัวเอง
az ≈ −1 ตอนรถตั้งปกติ | ติดบอร์ดคว่ำ (ด้านชิปลง) | แปะใหม่ให้ด้านชิปขึ้น
inv สลับเองตอนชน | บอร์ดหลวม/โฟมหลุด ทำ ให้สั่นมาก | แปะโฟมใหม่ + กาวมุม · ทำ T2 ซ้ำ
rpm = 0 ตลอด | แม่เหล็กหันขั้ว N เข้าหา sensor · ระยะห่างเกิน · ไม่มี 5 V ที่ขา 1 · ไม่มี pull-up | ตรวจขั้วตาม §6.2 · วัดระยะ 2.5 · วัด 5 V · วัด GPIO32 ลอยได้ 3.3 V
rpm เป็น 2 เท่า | แม่เหล็กทั้งสองลูกหันขั้ว S ออก | กลับลูกที่ 2 ให้ขั้ว N ออก
rpm กระโดด / มีค่าเมื่อใบไม่หมุน | noise จากสายเฟส D3536 หรือมอเตอร์ขับ · สาย สัญญาณขนานสายกำ ลัง · แม่เหล็กในมอเตอร์ D3536 สวิตช์ sensor | จัดสายตาม §8 · บิดเกลียวกับ GND · ใส่ ferrite · ถ้ายังมี ให้เลื่อนเสาห่างมอเตอร์ (ต้องแก้แบบ)
อ่านรอบต่ำ กว่าเครื่องวัด | เครื่องวัดรอบอ่านใบแทนรอก (สายพานลื่น) · พัลส์ บางลูกหลุดเพราะสนามอ่อน | วัดที่รอกให้ตรงกัน · ลดระยะเฉพาะเมื่อยืนยันว่ารอกไม่แตะ เมื่อกดพื้นถาด หรือใช้แม่เหล็กแรงขึ้น
esc/motor = nan หรือ −127 | DQ หลุด · ไม่มี R 4.7k · ต่อขากลับ (ร้อนมาก) | ปิดไฟทันทีถ้าตัว sensor ร้อน · ตรวจลำ ดับขา · ใส่ R 4.7k
อุณหภูมิ ESC/มอเตอร์สลับกัน | ESC_TEMP_INDEX ไม่ตรง | ทดสอบเอานิ้วอุ่น แล้วแก้ ESC_TEMP_INDEX
vbat ผิดหรือ 0 | จุดกลางไม่ได้ต่อ GPIO34 · ตัวต้านทานผิดค่า · ต่อ ก่อน link แต่ถอด link อยู่ | วัดแรงดันที่ขา (ควร ≈ vbat/5.545) · แก้ VBAT_DIVIDER ตาม §10.4
เตือนแบตต่ำ ตอนแบตยังเต็ม | แรงดันตกค้างนานจากมอเตอร์ติด · สายแบตเส้น เล็ก/ขั้วต่อหลวม | วัดแรงดันตกที่ XT30 ขณะเร่ง · ตรวจขั้วต่อ
Sensor หลุดหลังชน | กาว/เทปไม่พอ · สายดึง | ใช้ทางเลือกสกรู M2 ของเสา S2 · เพิ่มกาวมุม IMU · เผื่อ ห่วงสาย
ค่าผิดหลังชน | เสา S2 เอียง/พื้นยุบ · IMU ขยับบนโฟม · ESC/ มอเตอร์ขยับจาก sensor | ทำ Checklist §14 หมวด S1/S2 ใหม่ แล้วทำ §10 ซ้ำ

# @@HA@@A ภาคผนวก A — แบบบันทึกค่าที่วัดจาก Robot V4 จริง

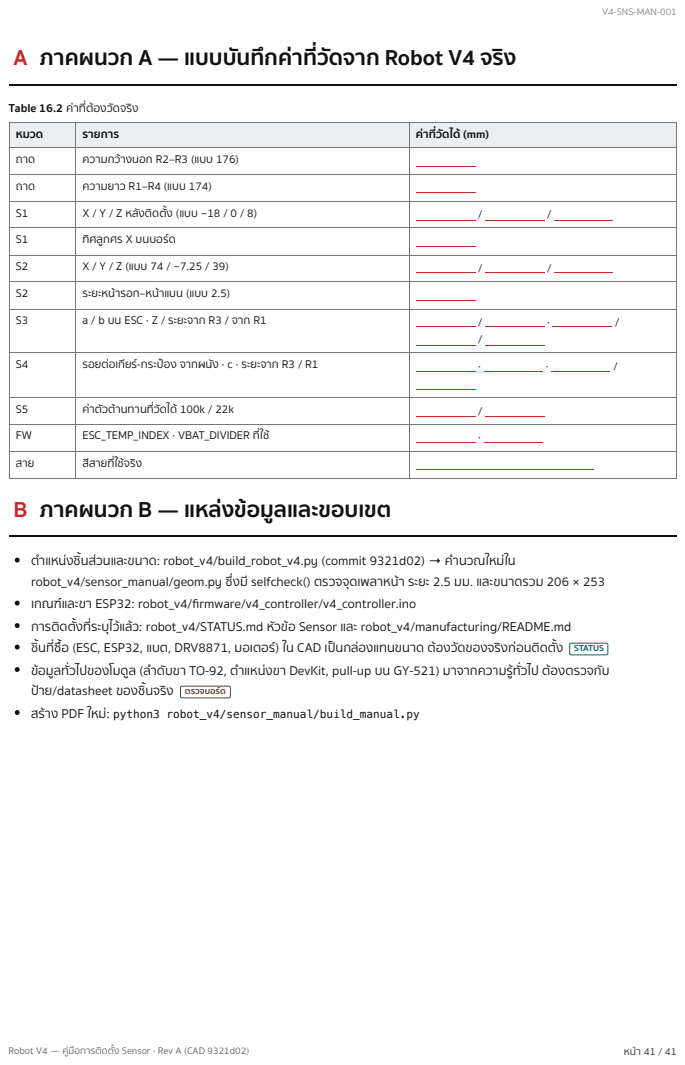
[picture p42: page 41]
Robot V4 — คู่มือการติดตั้ง Sensor · Rev A (CAD 9321d02)

Table 16.2 ค่าที่ต้องวัดจริง

หมวด | รายการ | ค่าที่วัดได้ (mm)
ถาด | ความกว้างนอก R2–R3 (แบบ 176)
ถาด | ความยาว R1–R4 (แบบ 174)
S1 | X / Y / Z หลังติดตั้ง (แบบ −18 / 0 / 8) | / /
S1 | ทิศลูกศร X บนบอร์ด
S2 | X / Y / Z (แบบ 74 / −7.25 / 39) | / /
S2 | ระยะหน้ารอก–หน้าแบน (แบบ 2.5)
S3 | a / b บน ESC · Z / ระยะจาก R3 / จาก R1 | / · / /

S4 | รอยต่อเกียร์-กระป๋อง จากผนัง · c · ระยะจาก R3 / R1 | · · /

S5 | ค่าตัวต้านทานที่วัดได้ 100k / 22k | /
FW | ESC_TEMP_INDEX · VBAT_DIVIDER ที่ใช้ | ·
สาย | สีสายที่ใช้จริง

@@HB@@B ภาคผนวก B — แหล่งข้อมูลและขอบเขต

ตำ แหน่งชิ้นส่วนและขนาด: robot_v4/build_robot_v4.py (commit 9321d02) → คำนวณใหม่ใน
robot_v4/sensor_manual/geom.py ซึ่งมี selfcheck() ตรวจจุดเพลาหน้า ระยะ 2.5 มม. และขนาดรวม 206 × 253
เกณฑ์และขา ESP32: robot_v4/firmware/v4_controller/v4_controller.ino
การติดตั้งที่ระบุไว้แล้ว: robot_v4/STATUS.md หัวข้อ Sensor และ robot_v4/manufacturing/README.md
ชิ้นที่ซื้อ (ESC, ESP32, แบต, DRV8871, มอเตอร์) ใน CAD เป็นกล่องแทนขนาด ต้องวัดของจริงก่อนติดตั้ง STATUS
ข้อมูลทั่วไปของโมดูล (ลำ ดับขา TO-92, ตำ แหน่งขา DevKit, pull-up บน GY-521) มาจากความรู้ทั่วไป ต้องตรวจกับ
ป้าย/datasheet ของชิ้นจริง ตรวจบอร์ด
สร้าง PDF ใหม่: python3 robot_v4/sensor_manual/build_manual.py

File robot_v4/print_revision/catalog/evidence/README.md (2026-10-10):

# ภาพร้าน FromFactory ที่ตรวจ 8 ต.ค. 2026

ภาพจากlistingรวมJGA25-370หลายrpm ไม่ใช่drawingมีscale และไม่ใช่ภาพอะไหล่ที่ซื้อจริง จึงใช้ยืนยันเพียงหน้าตาสินค้า ไม่ใช้วัดpixelเพื่อเปลี่ยนระยะรูหรือเพลา

แหล่งimageตามลำดับ: https://do.lnwfile.com/_/do/_raw/44/r1/6n.jpg, https://do.lnwfile.com/_/do/_raw/eo/hi/dm.jpg, https://do.lnwfile.com/_/do/_raw/qu/r3/rx.jpg

## หลักฐานแบตเตอรี่ FPVONLY

`fpvonly_battery_8503s.json` เก็บเฉพาะข้อมูลตัวเลือกSKU-08923จากHTMLสาธารณะที่อ่าน8ต.ค.2026:490บาท, remain9, ชื่อDC850-150C3S UC และchecksumของHTMLต้นทาง ข้อมูลราคา/stockนี้ไม่ใช่หลักฐานวัดของจริง ไม่ใช่การจอง และไม่มีdimension/massตรงรุ่น

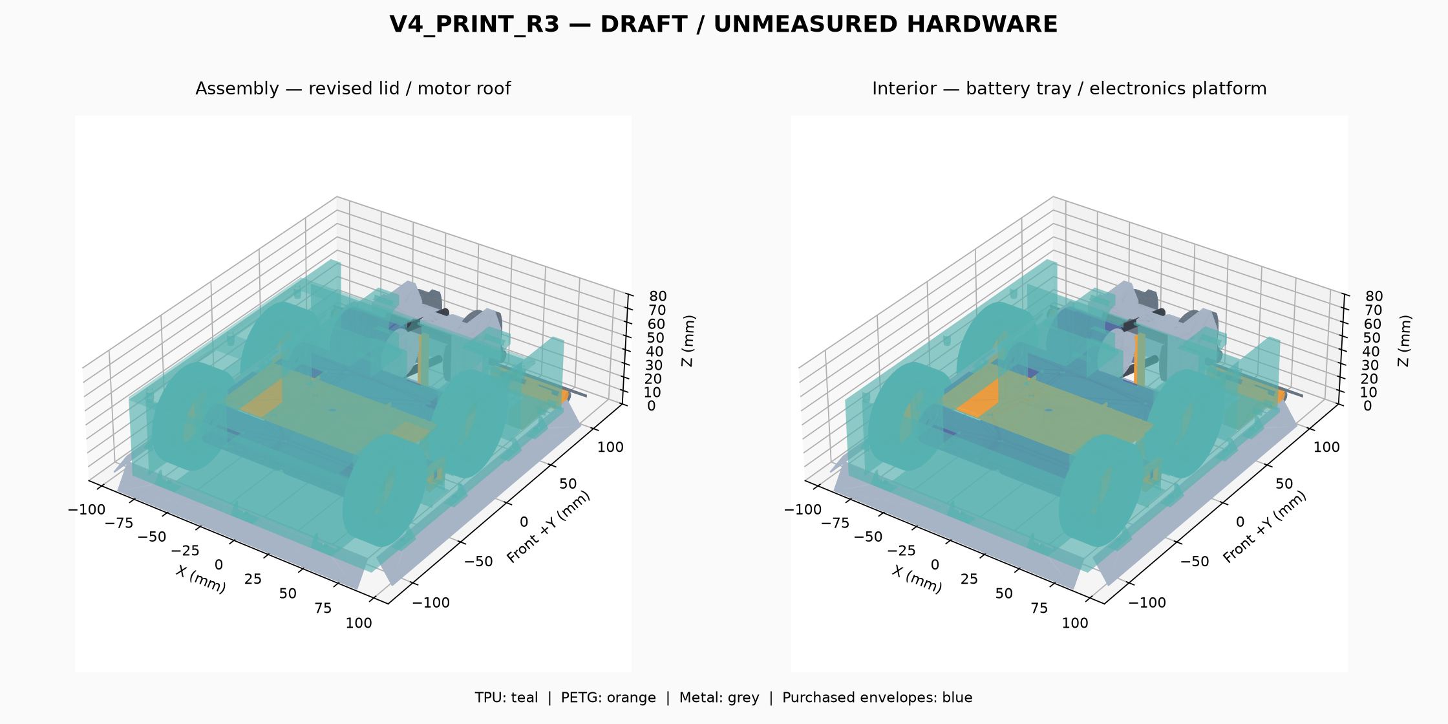
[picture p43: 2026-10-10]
robot_v4/print_revision/r3/output_R3/assembly_preview.png

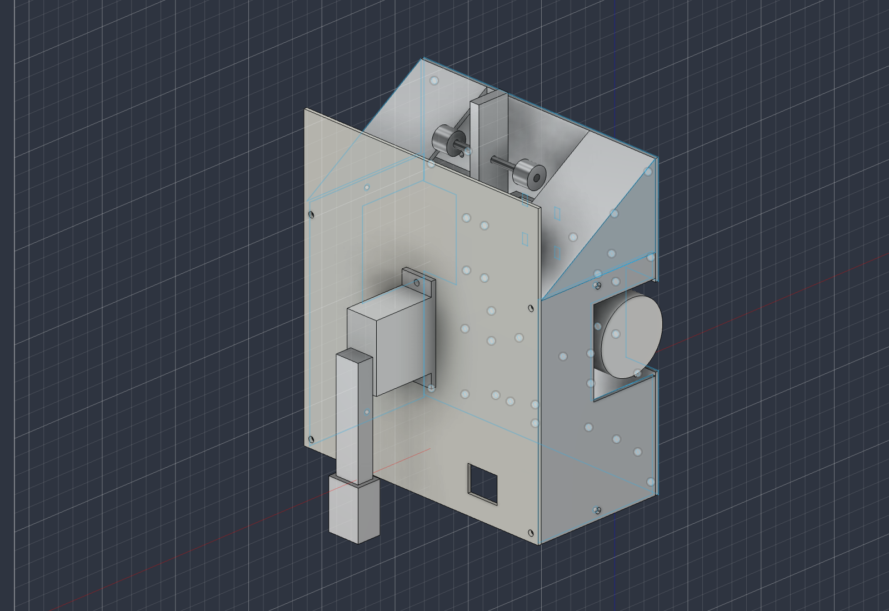
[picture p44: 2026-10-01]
exports/views/assembly_06_cover_and_hammer.png

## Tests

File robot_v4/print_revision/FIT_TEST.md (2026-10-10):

# ทดลองระยะสวมก่อนผลิตชุดใหญ่

ใช้ `output/TRIAL_ONLY` กับเครื่อง เส้น profile และท่าพิมพ์เดียวกับชุดใหญ่ ชื่อไฟล์ระบุค่าทดลอง ไม่ใช่ค่าที่รับรองแล้ว

1. **เพลา D:** ลอง clearance เส้นผ่านศูนย์กลาง 0.0/0.1/0.2/0.3 มม. ค่าด้านแบนเริ่มครึ่งหนึ่งของ clearance เลือกชิ้นที่สวมได้ด้วยมือ ไม่ต้องตอก บันทึกเพลาทั้งสี่ตัว ไม่ถือว่าเพลาชิ้นแรกแทนได้ทุกตัว
2. **แกนบานพับ:** ลอง clearance 0.0/0.1/0.2/0.3 มม. มีทั้งรูพิมพ์แนวตั้งและแนวนอน ใช้รูแนวนอนแทนบล็อก รูแนวตั้งแทน carrier เลือกค่าที่ผ่านทั้งคู่แล้วทดสอบบล็อกจริงหนึ่งข้างพร้อม carrier สองชิ้น
3. **Insert:** รู nominal OD−0.2…OD+0.2 มม. ทีละ 0.1 มม. ทดลอง PETG/TPU ตามวัสดุและทิศรูจริง ฝัง insert ด้วยวิธีที่ร้านใช้จริง ต้องไม่แตก ไม่หมุนตามสกรู ไม่หลุดเมื่อขันฝาหรือ wedgelet
4. **ยาง:** วงแหวนทดลอง ID43.4/43.6/43.8/44.0 มม. หนา 4 มม. เลือกค่าที่สวมดุม Ø44 ได้และไม่หมุนฟรี จากนั้นพิมพ์ยางเต็ม 16 มม. หนึ่งชิ้นยืนยันซ้ำก่อนครบสี่ล้อ
5. **น็อตดุมและสกรูล็อก:** ใส่ M3 จริงผ่านช่องข้างดุม หันหน้าราบของน็อตตามช่อง ใส่สกรูตัวหนอนทางรูที่ขอบดุม ขันให้แตะด้านแบนของเพลา ดุมต้องไม่หมุนหรือเลื่อนโดยการทดสอบแรงมือ ติดตามรอยแตก/การยุบ หากน็อตหมุนให้ปรับช่องตามของจริงและพิมพ์ซ้ำ
6. **ฝา:** ใช้ชิ้น TPU wall/lid ทดสอบ insert และน็อตฝา ขัน/คลายซ้ำอย่างน้อย 5 รอบ ต้องไม่หมุนฟรีหรือดึง insert หลุด
7. **Wedgelet:** ใส่แกน เหล็ก และสกรูจริง ปลายต้องลงพื้นด้วยน้ำหนักตัวเอง ยกได้จนตัวหยุดโดยไม่ติดและไม่ดึง insert หลุด ผลแรงมือเป็นเกณฑ์ประกอบเท่านั้น ไม่ใช่การรับรองแรงชน

| ผลตรวจ | ผ่าน/ไม่ผ่าน | ค่าที่เลือก | อะไหล่/เครื่อง/วัสดุ | หลักฐาน |
|---|---|---|---|---|
| เพลา D สวมได้ ทั้ง 4 ตัว | รอ | รอ | รอ | รอ |
| ดุมไม่หมุน / ไม่เลื่อนเมื่อขัน | รอ | รอ | รอ | รอ |
| ยางเต็มไม่หมุนฟรี | รอ | รอ | รอ | รอ |
| บานพับหมุนคล่อง | รอ | รอ | รอ | รอ |
| Wedgelet ขันได้แน่น | รอ | รอ | รอ | รอ |
| Insert PETG/TPU ไม่หมุน | รอ | รอ | รอ | รอ |
| ฝาขัน/คลาย 5 รอบ | รอ | รอ | รอ | รอ |

นำค่าที่เลือกลง `inputs.json` → `fit` แล้วสร้างใหม่เพื่อยืนยันว่าการปรับรูไม่ทำให้ CAD ชนหรือเนื้อบานพับลดลง ก่อนลงผล `verified` และ SHA ของแบบสุดท้าย หากเปลี่ยนตัวแปรหลังทดสอบ ให้ทดสอบจุดที่เปลี่ยนใหม่

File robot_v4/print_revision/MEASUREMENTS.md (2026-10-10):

# ตารางวัดอะไหล่ — V4 Print R1

ทุกแถวด้านล่างยังรอวัดจริง ค่า nominal ใน JSON ใช้สร้างต้นแบบเท่านั้น กรอกค่ามม./กรัมใน actual และบันทึกไฟล์หลักฐานก่อนเปลี่ยน verified เป็น true

| รายการ | ต้องวัด/ยืนยัน | ค่า actual | หลักฐาน |
|---|---|---|---|
| drive_Front_L | length_mm, diameter_mm, mass_g, shaft_diameter_mm, shaft_flat_depth_mm, shaft_projection_mm, boss_diameter_mm, boss_projection_mm, mount_holes_yz_mm, mount_thread_diameter_mm, mount_thread_depth_mm | รอ | รอ |
| drive_Front_R | length_mm, diameter_mm, mass_g, shaft_diameter_mm, shaft_flat_depth_mm, shaft_projection_mm, boss_diameter_mm, boss_projection_mm, mount_holes_yz_mm, mount_thread_diameter_mm, mount_thread_depth_mm | รอ | รอ |
| drive_Rear_L | length_mm, diameter_mm, mass_g, shaft_diameter_mm, shaft_flat_depth_mm, shaft_projection_mm, boss_diameter_mm, boss_projection_mm, mount_holes_yz_mm, mount_thread_diameter_mm, mount_thread_depth_mm | รอ | รอ |
| drive_Rear_R | length_mm, diameter_mm, mass_g, shaft_diameter_mm, shaft_flat_depth_mm, shaft_projection_mm, boss_diameter_mm, boss_projection_mm, mount_holes_yz_mm, mount_thread_diameter_mm, mount_thread_depth_mm | รอ | รอ |
| weapon_motor | length_mm, diameter_mm, mass_g, shaft_diameter_mm, shaft_projection_mm, boss_diameter_mm, mount_holes_yz_mm, mount_thread_diameter_mm, mount_thread_depth_mm | รอ | รอ |
| battery | dimensions_mm, mass_g, connector_keepout_mm, connector_x_offset_mm, connector_side | รอ | รอ |
| esc | dimensions_mm, mass_g, connector_keepout_mm, connector_x_offset_mm, connector_side | รอ | รอ |
| esp32 | dimensions_mm, mass_g, connector_keepout_mm, connector_x_offset_mm, connector_side | รอ | รอ |
| drv_left | dimensions_mm, mass_g, connector_keepout_mm, connector_x_offset_mm, connector_side | รอ | รอ |
| drv_right | dimensions_mm, mass_g, connector_keepout_mm, connector_x_offset_mm, connector_side | รอ | รอ |
| imu | dimensions_mm, mass_g, connector_keepout_mm, connector_x_offset_mm, connector_side | รอ | รอ |
| disconnect | dimensions_mm, mass_g, connector_keepout_mm, connector_x_offset_mm, connector_side | รอ | รอ |
| bearing_608 | outer_diameter_mm, inner_diameter_mm, width_mm, mass_g_each | รอ | รอ |
| hinge_pin | diameter_mm, length_mm, mass_g_pair | รอ | รอ |
| insert_m3 | outer_diameter_mm, length_mm | รอ | รอ |
| nut_m3 | across_flats_mm, height_mm | รอ | รอ |
| hall_sensor | dimensions_mm, mass_g, magnet_diameter_mm, magnet_thickness_mm | รอ | รอ |
| dead_shaft | mass_g, diameter_mm, length_mm, head_across_flats_mm, head_thickness_mm, nut_across_flats_mm, nut_thickness_mm, washer_outer_diameter_mm, washer_inner_diameter_mm, washer_thickness_mm, thread_length_mm | รอ | รอ |
| clips | mass_g | รอ | รอ |
| belt | mass_g | รอ | รอ |
| skid | mass_g | รอ | รอ |
| rotor_screws | mass_g | รอ | รอ |
| baseline_fasteners | mass_g | รอ | รอ |
| revision_fasteners | mass_g | รอ | รอ |
| wiring | mass_g | รอ | รอ |
| aux_sensors | mass_g | รอ | รอ |
| straps | mass_g | รอ | รอ |

## วิธีเก็บข้อมูล

- มอเตอร์ขับ: วัดแยกทั้ง 4 ตัว ระยะรูใช้ศูนย์รู บันทึกพิกัด dy/dz จากศูนย์เพลา พร้อมเกลียว ความลึกเกลียว และความยาวเพลาที่ยื่นจากหน้ามอเตอร์
- มอเตอร์อาวุธ: วัดหน้าที่ประกบเพลตและปลายเพลา รวมพื้นที่หัวน็อต/สายไฟ ความยาวมอเตอร์ในแบบวัดระหว่างหน้าประกบและท้าย ไม่รวมเพลา
- บอร์ด/แบต/ESC: วัดรวมส่วนยื่น และทำ connector_keepout_mm เป็นกล่อง XYZ สำหรับหัวปลั๊กและช่วงสายที่ต้องดัด ระบุ connector_side front/rear และ connector_x_offset_mm จากกลางอุปกรณ์
- Insert: วัด OD ที่ปุ่มนูนสูงสุด ความยาว และชนิดเกลียว ยืนยันด้วยชิ้นทดลอง ไม่เลือกขนาดรูจาก OD เพียงอย่างเดียว
- น้ำหนัก ancillary: ชั่งชุดสกรู แหวน น็อต สาย และสายรัดจริงแยกหมวด ห้ามใส่ค่า allowances เป็น actual โดยไม่ชั่ง
- หลักฐานเก็บใน evidence/; ชื่อไฟล์ใน JSON อ้างจาก print_revision/ เช่น evidence/drive_front_left_measurement.jpg
- ขนาดที่เปลี่ยนแล้วทำให้ layout ไม่ผ่านจะต้องปรับแบบและตรวจใหม่ โปรแกรมจะไม่ย่ออุปกรณ์ให้พอดีโดยอัตโนมัติ

## งบรวม

| หมวด | จำนวน | ราคารวมจริง บาท | หลักฐาน |
|---|---:|---:|---|
| drive_motors | 4 | รอ | รอ |
| weapon_motor | 1 | รอ | รอ |
| esc | 1 | รอ | รอ |
| battery | 1 | รอ | รอ |
| drive_drivers | 1 | รอ | รอ |
| sensors | 1 | รอ | รอ |
| controller | 1 | รอ | รอ |
| charger | 1 | รอ | รอ |
| disconnect_fuse | 1 | รอ | รอ |
| wiring_connectors | 1 | รอ | รอ |
| bearings | 1 | รอ | รอ |
| belt | 1 | รอ | รอ |
| metal_cutting | 1 | รอ | รอ |
| machining | 1 | รอ | รอ |
| fasteners_inserts | 1 | รอ | รอ |
| hinge_pins_clips | 1 | รอ | รอ |
| skid | 1 | รอ | รอ |
| trial_prints | 1 | รอ | รอ |
| full_prints | 1 | รอ | รอ |
| shipping | 1 | รอ | รอ |
| contingency | 1 | รอ | รอ |

ESP32 และเครื่องชาร์จที่มีอยู่แล้วสามารถกรอก 0 บาท พร้อมบันทึกว่ามีอยู่จริง ไม่ถือว่ารายการที่ยังไม่มีราคามีต้นทุนศูนย์ ราคาต้องรวมชิ้นทดลอง เก็บงาน ค่าส่ง และเผื่อรายการเล็ก เป้าหมายยอดไม่เกิน 6,000 บาท

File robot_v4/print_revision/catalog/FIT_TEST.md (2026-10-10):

**เฉพาะR2: ห้ามใช้ผลทดลองR1แทนหลังเปลี่ยนinsert/แท่นอุปกรณ์**

# ทดลองระยะสวมก่อนผลิตชุดใหญ่

ใช้ `output_R2/TRIAL_ONLY` กับเครื่อง เส้น profile และท่าพิมพ์เดียวกับชุดใหญ่ ชื่อไฟล์ระบุค่าทดลอง ไม่ใช่ค่าที่รับรองแล้ว

1. **เพลา D:** ลอง clearance เส้นผ่านศูนย์กลาง 0.0/0.1/0.2/0.3 มม. ค่าด้านแบนเริ่มครึ่งหนึ่งของ clearance เลือกชิ้นที่สวมได้ด้วยมือ ไม่ต้องตอก บันทึกเพลาทั้งสี่ตัว ไม่ถือว่าเพลาชิ้นแรกแทนได้ทุกตัว
2. **แกนบานพับ:** ลอง clearance 0.0/0.1/0.2/0.3 มม. มีทั้งรูพิมพ์แนวตั้งและแนวนอน ใช้รูแนวนอนแทนบล็อก รูแนวตั้งแทน carrier เลือกค่าที่ผ่านทั้งคู่แล้วทดสอบบล็อกจริงหนึ่งข้างพร้อม carrier สองชิ้น
3. **Insert:** รู R2 Ø4.4/4.5/4.6/4.7/4.8 มม. สำหรับinsertOD5ยาว4mm (ค่าเริ่มทดลอง ยังไม่สอบเทียบ) ทีละ 0.1 มม. ทดลอง PETG/TPU ตามวัสดุและทิศรูจริง ฝัง insert ด้วยวิธีที่ร้านใช้จริง ต้องไม่แตก ไม่หมุนตามสกรู ไม่หลุดเมื่อขันฝาหรือ wedgelet
4. **ยาง:** วงแหวนทดลอง ID43.4/43.6/43.8/44.0 มม. หนา 4 มม. เลือกค่าที่สวมดุม Ø44 ได้และไม่หมุนฟรี จากนั้นพิมพ์ยางเต็ม 16 มม. หนึ่งชิ้นยืนยันซ้ำก่อนครบสี่ล้อ
5. **น็อตดุมและสกรูล็อก:** ใส่ M3 จริงผ่านช่องข้างดุม หันหน้าราบของน็อตตามช่อง ใส่สกรูตัวหนอนทางรูที่ขอบดุม ขันให้แตะด้านแบนของเพลา ดุมต้องไม่หมุนหรือเลื่อนโดยการทดสอบแรงมือ ติดตามรอยแตก/การยุบ หากน็อตหมุนให้ปรับช่องตามของจริงและพิมพ์ซ้ำ
6. **ฝา:** ใช้ชิ้น TPU wall/lid ทดสอบ insert และน็อตฝา ขัน/คลายซ้ำอย่างน้อย 5 รอบ ต้องไม่หมุนฟรีหรือดึง insert หลุด
7. **Wedgelet:** ใส่แกน เหล็ก และสกรูจริง ปลายต้องลงพื้นด้วยน้ำหนักตัวเอง ยกได้จนตัวหยุดโดยไม่ติดและไม่ดึง insert หลุด ผลแรงมือเป็นเกณฑ์ประกอบเท่านั้น ไม่ใช่การรับรองแรงชน

| ผลตรวจ | ผ่าน/ไม่ผ่าน | ค่าที่เลือก | อะไหล่/เครื่อง/วัสดุ | หลักฐาน |
|---|---|---|---|---|
| เพลา D สวมได้ ทั้ง 4 ตัว | รอ | รอ | รอ | รอ |
| ดุมไม่หมุน / ไม่เลื่อนเมื่อขัน | รอ | รอ | รอ | รอ |
| ยางเต็มไม่หมุนฟรี | รอ | รอ | รอ | รอ |
| บานพับหมุนคล่อง | รอ | รอ | รอ | รอ |
| Wedgelet ขันได้แน่น | รอ | รอ | รอ | รอ |
| Insert PETG/TPU ไม่หมุน | รอ | รอ | รอ | รอ |
| ฝาขัน/คลาย 5 รอบ | รอ | รอ | รอ | รอ |

นำค่าที่เลือกลง `inputs_R2.json` → `fit` แล้วสร้างใหม่เพื่อยืนยันว่าการปรับรูไม่ทำให้ CAD ชนหรือเนื้อบานพับลดลง ก่อนลงผล `verified` และ SHA ของแบบสุดท้าย หากเปลี่ยนตัวแปรหลังทดสอบ ให้ทดสอบจุดที่เปลี่ยนใหม่

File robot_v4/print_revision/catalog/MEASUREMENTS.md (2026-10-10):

**ข้อมูลเว็บR2อยู่ในcatalog.values; actualทั้ง27รายการยังว่าง**

อ่านTHAI_PARTS_RESEARCH.mdและsources.jsonเพื่อแยกค่าหน้าเว็บจากnominal/ค่าที่วัดจริง ค่าเว็บไม่ใช่หลักฐานverified ราคาเป็นรายการซื้อครบเพื่อวางงบ; สถานะของที่มีอยู่แล้วต้องยืนยันก่อนหักค่าใช้จ่าย

# ตารางวัดอะไหล่ — V4 Print R2

ทุกแถวด้านล่างยังรอวัดจริง ค่า nominal ใน JSON ใช้สร้างต้นแบบเท่านั้น กรอกค่ามม./กรัมใน actual และบันทึกไฟล์หลักฐานก่อนเปลี่ยน verified เป็น true

| รายการ | ต้องวัด/ยืนยัน | ค่า actual | หลักฐาน |
|---|---|---|---|
| drive_Front_L | length_mm, diameter_mm, mass_g, shaft_diameter_mm, shaft_flat_depth_mm, shaft_projection_mm, boss_diameter_mm, boss_projection_mm, mount_holes_yz_mm, mount_thread_diameter_mm, mount_thread_depth_mm | รอ | รอ |
| drive_Front_R | length_mm, diameter_mm, mass_g, shaft_diameter_mm, shaft_flat_depth_mm, shaft_projection_mm, boss_diameter_mm, boss_projection_mm, mount_holes_yz_mm, mount_thread_diameter_mm, mount_thread_depth_mm | รอ | รอ |
| drive_Rear_L | length_mm, diameter_mm, mass_g, shaft_diameter_mm, shaft_flat_depth_mm, shaft_projection_mm, boss_diameter_mm, boss_projection_mm, mount_holes_yz_mm, mount_thread_diameter_mm, mount_thread_depth_mm | รอ | รอ |
| drive_Rear_R | length_mm, diameter_mm, mass_g, shaft_diameter_mm, shaft_flat_depth_mm, shaft_projection_mm, boss_diameter_mm, boss_projection_mm, mount_holes_yz_mm, mount_thread_diameter_mm, mount_thread_depth_mm | รอ | รอ |
| weapon_motor | length_mm, diameter_mm, mass_g, shaft_diameter_mm, shaft_projection_mm, boss_diameter_mm, mount_holes_yz_mm, mount_thread_diameter_mm, mount_thread_depth_mm | รอ | รอ |
| battery | dimensions_mm, mass_g, connector_keepout_mm, connector_x_offset_mm, connector_side | รอ | รอ |
| esc | dimensions_mm, mass_g, connector_keepout_mm, connector_x_offset_mm, connector_side | รอ | รอ |
| esp32 | dimensions_mm, mass_g, connector_keepout_mm, connector_x_offset_mm, connector_side | รอ | รอ |
| drv_left | dimensions_mm, mass_g, connector_keepout_mm, connector_x_offset_mm, connector_side | รอ | รอ |
| drv_right | dimensions_mm, mass_g, connector_keepout_mm, connector_x_offset_mm, connector_side | รอ | รอ |
| imu | dimensions_mm, mass_g, connector_keepout_mm, connector_x_offset_mm, connector_side | รอ | รอ |
| disconnect | dimensions_mm, mass_g, connector_keepout_mm, connector_x_offset_mm, connector_side | รอ | รอ |
| bearing_608 | outer_diameter_mm, inner_diameter_mm, width_mm, mass_g_each | รอ | รอ |
| hinge_pin | diameter_mm, length_mm, mass_g_pair | รอ | รอ |
| insert_m3 | outer_diameter_mm, length_mm | รอ | รอ |
| nut_m3 | across_flats_mm, height_mm | รอ | รอ |
| hall_sensor | dimensions_mm, mass_g, magnet_diameter_mm, magnet_thickness_mm | รอ | รอ |
| dead_shaft | mass_g, diameter_mm, length_mm, head_across_flats_mm, head_thickness_mm, nut_across_flats_mm, nut_thickness_mm, washer_outer_diameter_mm, washer_inner_diameter_mm, washer_thickness_mm, thread_length_mm | รอ | รอ |
| clips | mass_g | รอ | รอ |
| belt | mass_g | รอ | รอ |
| skid | mass_g | รอ | รอ |
| rotor_screws | mass_g | รอ | รอ |
| baseline_fasteners | mass_g | รอ | รอ |
| revision_fasteners | mass_g | รอ | รอ |
| wiring | mass_g | รอ | รอ |
| aux_sensors | mass_g | รอ | รอ |
| straps | mass_g | รอ | รอ |

## วิธีเก็บข้อมูล

- มอเตอร์ขับ: วัดแยกทั้ง 4 ตัว ระยะรูใช้ศูนย์รู บันทึกพิกัด dy/dz จากศูนย์เพลา พร้อมเกลียว ความลึกเกลียว และความยาวเพลาที่ยื่นจากหน้ามอเตอร์
- มอเตอร์อาวุธ: วัดหน้าที่ประกบเพลตและปลายเพลา รวมพื้นที่หัวน็อต/สายไฟ ความยาวมอเตอร์ในแบบวัดระหว่างหน้าประกบและท้าย ไม่รวมเพลา
- บอร์ด/แบต/ESC: วัดรวมส่วนยื่น และทำ connector_keepout_mm เป็นกล่อง XYZ สำหรับหัวปลั๊กและช่วงสายที่ต้องดัด ระบุ connector_side front/rear และ connector_x_offset_mm จากกลางอุปกรณ์
- Insert: วัด OD ที่ปุ่มนูนสูงสุด ความยาว และชนิดเกลียว ยืนยันด้วยชิ้นทดลอง ไม่เลือกขนาดรูจาก OD เพียงอย่างเดียว
- น้ำหนัก ancillary: ชั่งชุดสกรู แหวน น็อต สาย และสายรัดจริงแยกหมวด ห้ามใส่ค่า allowances เป็น actual โดยไม่ชั่ง
- หลักฐานเก็บใน evidence/; ชื่อไฟล์ใน JSON อ้างจาก print_revision/ เช่น evidence/drive_front_left_measurement.jpg
- ขนาดที่เปลี่ยนแล้วทำให้ layout ไม่ผ่านจะต้องปรับแบบและตรวจใหม่ โปรแกรมจะไม่ย่ออุปกรณ์ให้พอดีโดยอัตโนมัติ

## งบรวม

| หมวด | จำนวน | ราคารวมจริง บาท | หลักฐาน |
|---|---:|---:|---|
| drive_motors | 4 | รอ | รอ |
| weapon_motor | 1 | รอ | รอ |
| esc | 1 | รอ | รอ |
| battery | 1 | รอ | รอ |
| drive_drivers | 1 | รอ | รอ |
| sensors | 1 | รอ | รอ |
| controller | 1 | รอ | รอ |
| charger | 1 | รอ | รอ |
| disconnect_fuse | 1 | รอ | รอ |
| wiring_connectors | 1 | รอ | รอ |
| bearings | 1 | รอ | รอ |
| belt | 1 | รอ | รอ |
| metal_cutting | 1 | รอ | รอ |
| machining | 1 | รอ | รอ |
| fasteners_inserts | 1 | รอ | รอ |
| hinge_pins_clips | 1 | รอ | รอ |
| skid | 1 | รอ | รอ |
| trial_prints | 1 | รอ | รอ |
| full_prints | 1 | รอ | รอ |
| shipping | 1 | รอ | รอ |
| contingency | 1 | รอ | รอ |

ผู้ใช้ยืนยันว่าไม่ได้ซื้ออะไหล่เลย ต้องรวม ESP32 และเครื่องชาร์จในต้นทุนด้วย; กรอก 0 บาทได้เฉพาะรายการที่ภายหลังมีหลักฐานว่าเป็นของที่มีอยู่จริง ไม่ถือว่ารายการที่ยังไม่มีราคามีต้นทุนศูนย์ ราคาต้องรวมชิ้นทดลอง เก็บงาน ค่าส่ง และเผื่อรายการเล็ก เป้าหมายยอดไม่เกิน 6,000 บาท

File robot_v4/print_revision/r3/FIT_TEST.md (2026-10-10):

**เฉพาะR3: ห้ามใช้ผลทดลองR1แทนหลังเปลี่ยนinsert/แท่นอุปกรณ์**

# ทดลองระยะสวมก่อนผลิตชุดใหญ่

ใช้ `output_R3/TRIAL_ONLY` กับเครื่อง เส้น profile และท่าพิมพ์เดียวกับชุดใหญ่ ชื่อไฟล์ระบุค่าทดลอง ไม่ใช่ค่าที่รับรองแล้ว

1. **เพลา D:** ลอง clearance เส้นผ่านศูนย์กลาง 0.0/0.1/0.2/0.3 มม. ค่าด้านแบนเริ่มครึ่งหนึ่งของ clearance เลือกชิ้นที่สวมได้ด้วยมือ ไม่ต้องตอก บันทึกเพลาทั้งสี่ตัว ไม่ถือว่าเพลาชิ้นแรกแทนได้ทุกตัว
2. **แกนบานพับ:** ลอง clearance 0.0/0.1/0.2/0.3 มม. มีทั้งรูพิมพ์แนวตั้งและแนวนอน ใช้รูแนวนอนแทนบล็อก รูแนวตั้งแทน carrier เลือกค่าที่ผ่านทั้งคู่แล้วทดสอบบล็อกจริงหนึ่งข้างพร้อม carrier สองชิ้น
3. **Insert:** รู R3 Ø4.4/4.5/4.6/4.7/4.8 มม. สำหรับinsertOD5ยาว4mm (ค่าเริ่มทดลอง ยังไม่สอบเทียบ) ทีละ 0.1 มม. ทดลอง PETG/TPU ตามวัสดุและทิศรูจริง ฝัง insert ด้วยวิธีที่ร้านใช้จริง ต้องไม่แตก ไม่หมุนตามสกรู ไม่หลุดเมื่อขันฝาหรือ wedgelet
4. **ยาง:** วงแหวนทดลอง ID43.4/43.5/43.6/43.7/43.8/43.9/44.0 มม. หนา 4 มม. เลือกค่าที่สวมดุม Ø44 ได้และไม่หมุนฟรี จากนั้นพิมพ์ยางเต็ม 16 มม. หนึ่งชิ้นยืนยันซ้ำก่อนครบสี่ล้อ
5. **น็อตดุมและสกรูล็อก:** ใส่ M3 จริงผ่านช่องข้างดุม หันหน้าราบของน็อตตามช่อง ใส่สกรูตัวหนอนทางรูที่ขอบดุม ขันให้แตะด้านแบนของเพลา ดุมต้องไม่หมุนหรือเลื่อนโดยการทดสอบแรงมือ ติดตามรอยแตก/การยุบ หากน็อตหมุนให้ปรับช่องตามของจริงและพิมพ์ซ้ำ
6. **ฝา:** ใช้ชิ้น TPU wall/lid ทดสอบ insert และน็อตฝา ขัน/คลายซ้ำอย่างน้อย 5 รอบ ต้องไม่หมุนฟรีหรือดึง insert หลุด
7. **Wedgelet:** ใส่แกน เหล็ก และสกรูจริง ปลายต้องลงพื้นด้วยน้ำหนักตัวเอง ยกได้จนตัวหยุดโดยไม่ติดและไม่ดึง insert หลุด ผลแรงมือเป็นเกณฑ์ประกอบเท่านั้น ไม่ใช่การรับรองแรงชน

| ผลตรวจ | ผ่าน/ไม่ผ่าน | ค่าที่เลือก | อะไหล่/เครื่อง/วัสดุ | หลักฐาน |
|---|---|---|---|---|
| เพลา D สวมได้ ทั้ง 4 ตัว | รอ | รอ | รอ | รอ |
| ดุมไม่หมุน / ไม่เลื่อนเมื่อขัน | รอ | รอ | รอ | รอ |
| ยางเต็มไม่หมุนฟรี | รอ | รอ | รอ | รอ |
| บานพับหมุนคล่อง | รอ | รอ | รอ | รอ |
| Wedgelet ขันได้แน่น | รอ | รอ | รอ | รอ |
| Insert PETG/TPU ไม่หมุน | รอ | รอ | รอ | รอ |
| ฝาขัน/คลาย 5 รอบ | รอ | รอ | รอ | รอ |

นำค่าที่เลือกลง `inputs_R3.json` → `fit` แล้วสร้างใหม่เพื่อยืนยันว่าการปรับรูไม่ทำให้ CAD ชนหรือเนื้อบานพับลดลง ก่อนลงผล `verified` และ SHA ของแบบสุดท้าย หากเปลี่ยนตัวแปรหลังทดสอบ ให้ทดสอบจุดที่เปลี่ยนใหม่

## R3 สองรอบและการผูกหลักฐาน

รอบ1พิมพ์couponและเลือกค่า→กรอกfit dimensionsแล้วสร้างCADใหม่→รอบ2พิมพ์ดุม/ยางเต็ม1ชุด บานพับพร้อมcarrierหนึ่งข้างและฝาจำลอง **จากbuildใหม่** ชุดรอบ2ที่ส่งในZIPเริ่มต้นยังเป็นค่าต้นแบบ ต้องสร้างใหม่ก่อนยืนยันผล fit_log.jsonเก็บSHAทั้งสองรอบ `fit/round2_sha256_build`ต้องตรงแบบสุดท้าย ทุกเพลาถูกบันทึกในtested_drive_shafts และlid_cycles>=5

บันทึกprinter/material brand/nozzle/slicer version/profileจริงทั้งสองวัสดุ และท่าพิมพ์ของชิ้นสวมในprofile_evidence; คำนวณprofile_sha256ผ่านreadiness.profile_signature(shop,folder)แล้วลงfit/slicer ถ้าprofile/nozzle/material/orientationเปลี่ยน ต้องทดลองใหม่ proofทั้งหมดต้องอยู่ในแฟ้มหลักฐาน ไม่ใช่ไฟล์fixtureของunit tests

ผลtrialไม่ยืนยันผลประกอบหุ่นเต็ม การฝังinsert/รูcarrierและเครื่องมือเป็น preflightก่อนPRINT_READY หลังประกอบจริงใช้assembly

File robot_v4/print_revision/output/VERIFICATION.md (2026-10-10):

# V4 Print R1 — ผลตรวจวันที่ 7 ต.ค. 2026

**DRAFT / ยังไม่ปล่อยผลิต** มีค่าขนาดอะไหล่ nominal ที่ยังไม่วัดจริง หลักฐานจากร้านและการทดลองยังไม่ครบ

Build SHA256: `1e42935da45872f495cb320ad9d2b20902f84db99dab7fda7827dc19a410a759`

| การตรวจ | ผล |
|---|---|
| Exact CAD valid solids / surface self-interference | ผ่าน |
| ชิ้นชนกันที่ไม่ตั้งใจ | 0 จุด |
| การประกบยางกับดุมที่ตั้งใจ | แยกรายงาน ไม่ถือเป็นการชนผิดแบบ |
| วงหมุนใบ เผื่อ1มม. | ไม่ชน |
| Wedgelet ทุก1°จาก−2°ถึง+14° | ไม่ชนทั้งสองข้าง |
| STL ตัวรถ | 17ไฟล์ ผ่านขอบเปิด/non-manifold/winding/หน้าซ้ำ/degenerate/ปริมาตร/Manifold validation |
| STL ทดลอง | 38ไฟล์ ผ่าน |
| STEP เปิดอ่านกลับด้วย OpenCascade | ผ่าน |
| DXF | 9ไฟล์ หน่วยมม.($INSUNITS=4) auditไม่มีข้อผิดพลาด |
| Regression/unit tests | 17กรณีผ่าน |
| Releaseเมื่อข้อมูลยังไม่ครบ | โปรแกรมปฏิเสธ(exit2) ไม่สร้างRELEASED |
| น้ำหนักประมาณ | 1966.16กรัม — ยังไม่ได้ใช้ค่าslicer/ชั่งจริง |
| โหลดล้อหลังเชิงสถิต / MuJoCo | 10.54% / 12.35% |
| ฟันกับพื้นต่ำสุดขณะเร่งใบในโมเดล | 2.08มม. ไม่มีcontactฟันกับพื้น |
| ขับกลับหัวใน1.5วินาที | 1.37เมตรในโมเดล |

## ยังไม่ผ่านเป้าหมาย / ต้องยืนยัน

- น้ำหนักยังเกินเป้าหมาย1,900กรัม และเหลือเผื่อเพียง33.84กรัมก่อน2กก. การเพิ่มของจริงอาจทำให้เกิน ต้องแทนค่าจากslicer/การชั่งและปรับแบบก่อนผลิต
- โหลดล้อหลังผ่านขั้นต่ำ10% แต่ยังไม่ถึงเป้าหมาย15% ไม่ถือว่าผลจำลองแทนการชั่งโหลดจริง
- ยังไม่มีข้อมูลactualของอะไหล่ครบ ผลทดลองfit ข้อมูลเครื่อง/วัสดุ/slicer และใบเสนอราคาทั้งโครงการไม่เกิน6,000บาท
- Exact CAD surface self-interferenceกับManifold mesh validationเป็นการตรวจรูปทรง ไม่ยืนยันความแข็งแรงของชั้นพิมพ์
- การทดสอบหลังชน เฟิร์มแวร์ และการรับรองพร้อมแข่งยังไม่ทำในrevisionนี้

## สิ่งที่เปลี่ยนจากV4เดิม

- เพลาหน้าy18, แกนมอเตอร์อาวุธ(y47.5,z42.5), ฝาหลังคาโค้งสูงสุดz63, ช่องหลบสายพาน
- บานพับและcarrierเสริมเนื้อรอบรู≥1.6, ดุมล็อกด้วยน็อตโลหะ/สกรูตัวหนอน
- ถาดแบต แท่นอุปกรณ์ เสารอง ฐานมอเตอร์ Hallpost และcollarมีจุดยึด
- M8×80พร้อมหัว/แหวน/น็อตและช่องบล็อกขันในTPU, รอกD30รากD27อัตรา1:1
- Uprightซ้าย/ขวาและbraceบน/ล่างใช้แบบแยกกัน ให้ใช้R1ทั้งชุด

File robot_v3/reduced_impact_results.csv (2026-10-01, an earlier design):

effective_contact_width_mm | vertical_tip_force_N | ideal_peak_elastic_bending_stress_MPa | ideal_peak_location_y_mm | ideal_tip_displacement_mm | ideal_elastic_yield_screen
120.0 | 300.0 | 3.9583 | 107.7774 | 0.005324 | below assumed yield for plow member only
120.0 | 583.0 | 7.6924 | 107.7774 | 0.010346 | below assumed yield for plow member only
120.0 | 1163.0 | 15.3451 | 107.7774 | 0.020638 | below assumed yield for plow member only
10.0 | 300.0 | 47.5 | 107.7774 | 0.063885 | below assumed yield for plow member only
10.0 | 583.0 | 92.3083 | 107.7774 | 0.124149 | below assumed yield for plow member only
10.0 | 1163.0 | 184.1417 | 107.7774 | 0.24766 | below assumed yield for plow member only

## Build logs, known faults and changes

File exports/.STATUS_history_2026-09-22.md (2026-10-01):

# สถานะงาน — ESP32 Mini BattleBot

อัปเดต 2026-09-22 23:38 — **รันผ่าน Fusion MCP กับเอกสาร `robot2` เรียบร้อย และ save แล้ว**

## สรุป

งานค้าง 4 ข้อแก้ครบแล้วในโมเดลจริง ไม่ใช่แค่ในสคริปต์

| # | งาน | ผล |
|---|---|---|
| 1 | Bracket ยึดมอเตอร์ A2212 | ✅ `Spinner_Motor_Cradle` สร้างแล้ว ไม่ชนอะไรเลย |
| 2 | จุดยึดโมดูล electronics | ✅ เจาะ 6 รู M2 ทะลุแผ่นฐาน |
| 2b | **รูยึด PCB ที่หายไป** | ✅ เจอว่าไม่เคยมีจริง → เจาะให้ 4 รู |
| 3 | วัสดุใบมีด | ✅ Al 6061 → **Aluminum 7075** (21.0 → 21.9 g) |
| 4 | Export ใหม่ | ✅ STEP / STL / DXF สร้างใหม่หมด ตรวจไฟล์แล้ว |
| 5 | **จุดยึดมอเตอร์ขับ TT** | ✅ `TT_Motor_Mount_L/R` + `TT_Motor_Clamp_L/R` |
| 6 | **รูน็อตที่หายไปทั้งระบบ** | ✅ ฝาบน / standoff / PCB standoff / หู servo / รูมุมแผ่นฐาน |
| 7 | **`Main_Disconnect`** | ✅ แขวนจากฝาบนด้วยเสา 2 ต้น |
| 8 | **`Spinner_ESC`** | ⚠️ ตั้งบนเสา 2 ต้นแนวกลาง — ดีที่สุดเท่าที่ทำได้ ดูหมายเหตุ |
| 9 | **F ลดน้ำหนัก** | ✅ −22.3 g จากการเซาะช่อง (cradle 51.3→35.8, แท่นมอเตอร์ 21.2→17.8 ต่อข้าง) |
| 10 | **ยึด `Battery_Holder`** | ✅ เสา Nylon 4 ต้น สูง 27.6 mm |
| 11 | **ชุดภาพ + เอกสารมิติ** | ✅ 11 ภาพ + `Dimensions_and_Fasteners.md` |
| 12 | **ย้าย `Main_Disconnect` + ช่องเข้าถึง** | ✅ ย้ายไป (42, −70) เจาะช่อง 20×16 mm บนฝาบน |
| 13 | **แผงปิดหลัง** | ✅ `Rear_Panel` Nylon เต็มความสูง 27.2 g |
| 14 | **ฝาครอบบอร์ด** | ✅ `Shield_*` 3 ชิ้น รวม 4.1 g |

Interference check: **7 คู่ แต่ปริมาตรซ้อนทับ = 0.000 mm³ ทุกคู่** คือหน้าสัมผัสที่ตั้งใจให้ชนกัน
(เพลา↔ลูกปืน, ใบมีด↔เพลา, ข้อต่อค้อน) **ไม่มีการทะลุกันจริงสักจุด** และไม่มีคู่ไหนเกี่ยวกับ cradle

## 1. `Spinner_Motor_Cradle`

สาเหตุที่ 3 รอบก่อนชน: วาง bracket ไว้**ด้านหลัง**มอเตอร์ (y < 12 mm) ซึ่งเป็นช่องที่
`Spinner_ESC` (y −16…10) กับ `Main_Disconnect` (y −8…12) อยู่ ช่องนั้นเต็ม
แต่ปริมาตร**ใต้**ตัวมอเตอร์ว่าง จึงทำเป็นแท่นรูปอานยกจากแผ่นฐานแทน

| รายการ | ค่าจริงจากโมเดล |
|---|---|
| Envelope | x −15…15, y 12…41, z 5…30.5 mm |
| รัศมีร่องอาน | 14.15 mm (ตัวถัง 13.75 + ระยะสวม 0.4) |
| มุมโอบ | ±55.6° |
| ความหนาขา | 2.08 mm (หลัง) / 3.58 mm (หน้า) |
| ยึด | 4× M3 ที่ (±11, 16) และ (±11, 37) ขันจากใต้แผ่นฐานเข้ารูเกลียวตันในตัว cradle |
| มวล | **51.3 g** (Aluminum 6061) |

**ข้อควรรู้ก่อนสร้างจริง:** ตอนแรกผมกะขอบหลังไว้ที่ y = 9 mm แต่ probe ตอนรันจริงจับได้ว่า
`TT_Motor_Can_L/R` ยื่นมาถึง y = 10 mm → ชน 1 mm เลยขยับขอบหลังมาชิดตัวมอเตอร์ที่ y = 12
เหลือช่องว่างกับมอเตอร์ขับ 2 mm พอดี **ถ้าขยับมอเตอร์ขับหรือ ESC เมื่อไหร่ ต้องเช็กจุดนี้ซ้ำ**

## 2. จุดยึดโมดูล electronics

เจาะรู M2 Ø2.2 ทะลุแผ่นฐาน 6 รู ตรงกับรูที่โมดูลมีอยู่แล้ว (สคริปต์อ่านตำแหน่งจากหน้า
cylindrical ในตัว body ไม่ได้เดา)

| โมดูล | ผล |
|---|---|
| RC_Receiver | เจาะ 2 รู ที่ (±9.5, −78) |
| Wheel_Motor_Drivers | เจาะ 2 รู ที่ (−59.5, −38), (−40.5, −38) |
| Power_Buck_BEC | เจาะ 2 รู ที่ (40.5, −38), (59.5, −38) |
| Main_Disconnect | **ข้าม** — อยู่สูง 40 mm บน bracket ต้องยึด bracket ไม่ใช่เจาะแผ่นฐานใต้มัน |

ที่ขอมาคือ "บอส" แต่ทำไม่ได้: แผ่นฐานอลูมิเนียม 2 mm ไม่มีเนื้อให้ปั้นบอส
ส่วนบอสพิมพ์แยกก็ต้องหาทางยึดกับแผ่นฐานอีกที วนกลับที่เดิม → รูทะลุคือคำตอบที่สร้างได้จริง

> ประกอบด้วยสกรู M2 หัวเรียบจากด้านล่าง + น็อตด้านบน **ต้องผ่าปากรูด้านล่าง**
> (90° Ø3.8 ลึกไม่เกิน 1.2 mm) เพราะเหลือระยะพ้นพื้นแค่ 3 mm — ยังไม่ได้ขึ้นรูปในโมเดล

## 2b. รูยึด PCB ที่รายงานเก่าบอกว่าทำแล้ว แต่ไม่เคยมีจริง

ตอนตรวจ ผมให้สคริปต์นับรูจริงในตัว solid แทนที่จะเชื่อ log — **`ESP32_Control_Board` มี 0 รู**

สาเหตุ: รอบก่อนวาด sketch บนระนาบ XY ที่ z = 0 แล้วตัดแบบ symmetric ±4 mm
แต่บอร์ดถูกย้ายขึ้นไปอยู่บน standoff สูง 3 mm แล้ว (z = 8.0…9.6) **การตัดจึงพลาดตัวบอร์ดไปทั้งหมด
ลบเนื้อไม่ได้เลย แต่ยังรายงานว่า "4 mount holes cut"**

แก้แล้ว: เจาะ Ø2.9 (ตรงกับรูในตัว standoff) 4 รู ที่ (±26, −59) และ (±26, −17)
ยืนยันด้วยการนับรูซ้ำหลังตัด: 0 → 4

## 3. ใบมีด → Aluminum 7075

เจอ `Aluminum 7075` ในไลบรารี Fusion โดยตรง ไม่ต้องสร้างวัสดุเอง

| วัสดุ | มวลใบมีด | พลังงาน (ที่ 1:1, 15,540 RPM) |
|---|---:|---:|
| Al 6061 (ของเดิม) | 21.05 g | 9.81 J |
| **Al 7075 (ใช้อันนี้)** | **21.90 g** | **10.21 J** |
| เหล็ก (ไม่ได้ใช้) | 61.19 g | 28.53 J |

ไม่เลือกเหล็กเพราะพลังงานขึ้นเกือบ 3 เท่า และเพิ่มน้ำหนัก ~40 g ในขณะที่เหลือ margin ไม่มาก

## 4. ไฟล์ export ใหม่ — ตรวจไฟล์จริงแล้ว

| ไฟล์ | ก่อน | หลัง |
|---|---|---|
| `DXF/Base_Plate_Al.dxf` | CIRCLE = **0** | CIRCLE = **22** (4 cradle + 6 โมดูล + 4 PCB standoff + 8 มอเตอร์ขับ) เส้นขอบ 12 จุด มีช่องล้อครบ |
| `DXF/Left/Right_Side_Plate_Al.dxf` | CIRCLE = 0 | CIRCLE = 2 |
| `DXF/Front_Wedge_L/R.dxf` | เส้นขอบ | เส้นขอบ (ดูหมายเหตุ) |
| `STL/Battery_Holder.stl` | 12 สามเหลี่ยม (กล่องเปล่า) | **76 สามเหลี่ยม** (ถาดจริง) |
| `STL/PCB_Standoff_*.stl` | 312 | 352 |
| `ESP32_Mini_BattleBot_Master.step` | 253 KB | 395 KB |

DXF เปลี่ยนวิธี export จาก "ใช้ sketch ต้นฉบับ" (ซึ่งไม่มีทางมีรูที่เจาะทีหลัง)
มาเป็น project จากหน้าจริงของชิ้นงาน

**หมายเหตุ wedge:** DXF ของปีกหน้ายังไม่มีรู และนั่นถูกต้องตามเรขาคณิต — รู M3 ของ wedge
เจาะตามแนวแกน Z แต่หน้าแบนที่กว้างที่สุดของมันคือระนาบ YZ รูจึงไม่ตัดผ่านหน้านั้น
สาเหตุลึกกว่านั้นคือ wedge ไม่ใช่ชิ้นงานแผ่น (ดูข้อ A)

> **เรื่องเวลาไฟล์:** export ทำตอน 22:30 หลังจากนั้นมีการ save เอกสารอีก 2 ครั้ง (22:32)
> แต่เป็นการเปิด/ปิดการมองเห็นชิ้นส่วนกับตั้งมุมกล้องเพื่อถ่ายภาพเท่านั้น
> **ไม่มีการเปลี่ยนเรขาคณิตหลัง 22:30** ไฟล์ที่ export ไว้จึงตรงกับโมเดลปัจจุบัน

## รายงานที่สร้างใหม่

- `exports/fusion_run_report.json` — ผลดิบทุกขั้น
- `exports/Mass_Report_Generated.md` — ตารางมวลรายชิ้น/รายระบบ + พลังงานอาวุธ

**มวลรวมปัจจุบัน:** 1,520.3 g (รวม envelope) / **1,429.3 g เฉพาะชิ้นจริง**
**จุด CG:** x = 0.0, y = +12.6, z = +36.0 mm

---

# ข้อตรวจพบที่ยังไม่แก้ (ต้องตัดสินใจก่อน)

## ✅ A. จุดยึดมอเตอร์ขับ TT — แก้แล้ว

**สิ่งที่เจอตอนตรวจ:** รอบก่อนบันทึกว่าเจาะรูยึดมอเตอร์ TT บนแผงข้างแล้ว แต่นับรูจริง
ในตัว solid ได้ **แผงข้างมีแค่ 2 รูต่อข้าง ทั้งคู่คือรูขัน standoff มุมตัวที่ z = 44 mm**
ไม่มีรูมอเตอร์ และต่อให้เจาะ กระปุกเกียร์ก็อยู่ห่างผิวในผนัง 17 mm สกรูไม่ถึง
ซ้ำบริเวณนั้นถูกเจาะเป็นช่องล้อไปแล้วตั้งแต่ z = 5 ถึง 47 mm

**ทำไมไม่ใช้รูของกระปุกเกียร์เอง:** กระปุกมีรู Ø3.4 สองรูจริง แต่มันวิ่ง**ตามแนวแกน X
ตลอดความยาว** ที่ y = ±8.75, z = 21 — นั่นคือรูสำหรับขายึดของผู้ผลิตที่ขันทะลุตามยาว
ปัญหาคือ **ปลายทั้งสองข้างของแนวสกรูนั้นตัน**: ข้างนอกเป็นล้อ ข้างในเป็นตัวมอเตอร์
ถ้าจะใส่ขายึดตรงช่องว่างระหว่างกระปุกกับตัวมอเตอร์ (x = −37…−28.7) มันจะ "พอดี"
เฉพาะในโมเดลนี้เท่านั้น เพราะโมเดลวาดกระปุกกับตัวมอเตอร์เป็นสองกล่องแยกกันโดยมีช่องว่าง
**ซึ่งมอเตอร์จริงไม่มี** → จะได้ของที่ดูถูกใน CAD แต่ประกอบจริงไม่ได้

**ทางที่เลือก: หนีบตัวกระปุกแทน** ไม่พึ่งรูของผู้ผลิตเลย

| ชิ้น | รายละเอียด |
|---|---|
| `TT_Motor_Mount_L/R` | แท่นรูปตัว U ยกจากแผ่นฐาน กระปุกวางลงในร่อง |
| Envelope | x ±34.7…±55, y ±16.5, z 5…30 mm |
| ร่องวางกระปุก | กว้าง ±11.5 mm (เผื่อข้างละ 0.5 mm) พื้นหนา 7 mm แก้มหนา 5 mm |
| ยึดแผ่นฐาน | 4× M3 ต่อข้าง ที่ (±51, ±14) และ (±38.7, ±14) — ตรวจแล้วว่าอยู่บนเนื้อแผ่นจริงทุกจุด |
| `TT_Motor_Clamp_L/R` | บาร์หนีบด้านบน 10 × 33 × 3 mm ขัน M3 ลงรูเกลียวในแก้มทั้งสอง |
| มวล | แท่น 21.23 g + บาร์ 2.53 g ต่อข้าง = **47.5 g ทั้งสองข้าง** |

**จุดที่เกือบพลาด — แรงกดของบาร์หนีบ:** ตอนแรกผมทำแก้มสูงถึง z = 30 เท่ากับหลังกระปุกพอดี
ผลคือขัน M3 แล้ว **บาร์จะไปชนแก้มก่อน ไม่ได้กดกระปุกเลย** แก้มกลายเป็นตัวหยุด
แรงกดเป็นศูนย์ กระปุกแค่ถูก "ครอบ" ไว้เฉย ๆ

แก้โดยลดแก้มลง 1.5 mm:

| | z (mm) |
|---|---|
| หลังกระปุก | 30.0 |
| หลังแก้ม | **28.5** (ต่ำกว่า 1.5 mm) |
| บาร์หนีบ | 30.0 → 33.0 |

บาร์จึงวางบนกระปุกก่อน แล้วสกรูดึงลง → **เกิดแรงกดจริง** โดยตัวบาร์อลูมิเนียม 3 mm
ทำหน้าที่เป็นสปริง

สคริปต์ตรวจ 2 ชั้นก่อนสร้าง: probe ปริมาตรว่าไม่ชนอะไร (ยกเว้นกระปุกที่ตั้งใจจะโอบ)
และ **ทดสอบ point containment ว่าตำแหน่งน็อตทั้ง 8 จุดอยู่บนเนื้อแผ่นฐานจริง**
(แผ่นฐานมีเนื้อเฉพาะ x ≥ ±56 เพราะโดนช่องล้อกินไป)

Interference หลังเพิ่ม: ยังคง 7 คู่ ปริมาตร 0.000 mm³ ทั้งหมด **ไม่มีคู่ใหม่**

## ✅ A2. รูน็อตที่หายไปทั้งระบบ — เจาะครบแล้ว

หลังเจอเคส PCB ผมไล่นับ cylindrical face ในทุก body แทนที่จะเชื่อ log **พบว่าเป็นปัญหา
เป็นระบบ ไม่ใช่เคสเดียว** สาเหตุเหมือนกันหมด: ชิ้นถูกย้ายด้วย Move feature ทีหลัง
แต่ sketch เจาะยังอยู่ที่ระนาบเดิม z = 0 การตัดจึงพลาดตัวชิ้นงาน ลบเนื้อไม่ได้
แต่ feature สร้างสำเร็จและ log รายงานว่าเรียบร้อย

| ชิ้น | ก่อน | หลัง (ตรวจนับใน solid แล้ว) |
|---|---|---|
| `Top_Cover` | **0 รู** | **8 รู** — 4 มุม M3.4 + 2 หู servo (49.5 mm) + 2 เสา disconnect |
| `Standoff_1…4` | แท่งตัน | **ตัวละ 3 รู** — เกลียว M3 ปลายบน/ล่าง + รูแนวนอนที่ z = 44 |
| `PCB_Standoff_1…4` | แท่งตัน | **ตัวละ 1 รู** — Ø2.1 นำร่อง M2.5 |
| `Hammer_Servo` | หูยึดไม่มีรู | **2 รู** Ø3.4 ตรงกับฝาบน |
| `Base_Plate_Al` | ไม่มีรูมุม | **+4 รู** Ø3.4 ที่ (±75, 35) และ (±75, −85) |

ตอนนี้ระบบยึด **ฐาน↔ผนัง↔ฝาบน** ครบวงจรแล้ว: ขัน M3 จากใต้แผ่นฐานขึ้นเกลียวล่างของเสา,
ขันจากข้างผ่านผนังเข้ารูแนวนอน, ขันจากบนผ่านฝาลงเกลียวบน

> **บทเรียนที่ควรจำ:** log ของ feature ที่รายงานว่าสำเร็จ **ไม่ใช่หลักฐานว่ามันลบเนื้อจริง**
> ต้องนับผลลัพธ์ใน solid เสมอ — แม้แต่ตัวนับที่ผมเรียกทันทีหลังตัดก็ยังอ่านค่าไม่ทันบางครั้ง
> ต้องอ่านแยกอีกรอบถึงจะเชื่อได้

## ✅ A3. ชิ้นที่ลอยอยู่ — ยึดแล้ว

**`Main_Disconnect`** — bracket ที่บันทึกเก่าบอกว่ายกมันขึ้นไปไม่เคยถูกสร้าง ตอนนี้
**แขวนจากฝาบน** ด้วยเสา Ø6 อลูมิเนียม 2 ต้น สูง 28 mm ที่ (±9.5, 2)
ขัน M2 ขึ้นจากตัวสวิตช์ และ M3 ลงจากฝาบน

*ทำไมไม่ตั้งเสาจากแผ่นฐาน:* ใต้ตัวสวิตช์เป็น TT motor can พอดี ตั้งเสาลงไม่ได้
ถ้าไม่ย้ายตำแหน่ง

⚠️ **ยังไม่ได้เจาะช่องเข้าถึงบนฝาบน** — สวิตช์ตัดไฟหลักต้องกดได้โดยไม่ต้องเปิดหุ่น

**`Spinner_ESC`** — ตั้งบนเสา Nylon Ø6 สูง 29.5 mm **2 ต้นบนแนวกลาง** ที่ (0, −9) และ (0, 7)

สคริปต์ลอง layout ที่ดีกว่าก่อน (เสา 3 ต้นที่มุม) แต่ probe จับได้ว่าเสาที่ x = ±18
จะทะลุ **บอร์ด ESP32** และเฉี่ยว TT motor can → ใช้ไม่ได้

⚠️ **ข้อจำกัดที่ต้องรู้:** ใต้ ESC มีแต่ของ — TT motor can อยู่ใต้ตรง ๆ (y ±10)
และบอร์ด ESP32 กินพื้นที่ทั้งหมดหลัง y = −13 เหลือช่องว่างจริงแค่ 7.4 mm
ระหว่าง can สองตัวที่ x ≈ 0 **เสาสองต้นบนแนวเดียวกันกันบอร์ดโยกไม่ได้**
(บอร์ดยื่นออกข้างละ ~22 mm) ทางแก้จริงคือย้ายตำแหน่ง ESC หรือแขวนจากฝาบนแบบ disconnect
— **อันนี้ต้องคุณตัดสินใจ**

## 🔴 B. ปีกหน้าหนัก 474 g = 32.5% ของทั้งคัน

`Front_Wedge_L/R` ข้างละ **236.9 g** เป็นอลูมิเนียม **ตันหนา 45 mm**
ปีกลิ่มจริงควรเป็นแผ่น 2–3 mm พับหรือเชื่อม น่าจะเหลือข้างละ 30–50 g
**แก้ข้อนี้ข้อเดียวได้น้ำหนักคืนมา ~380 g**

## 🔴 B2. มวลรวมทะลุเป้า 1,500 g แล้ว

มวลโมเดลรวมอยู่ที่ **1,520.3 g** (เฉพาะชิ้นจริง 1,429.3 g) จากเป้า 1,500 g

การลดน้ำหนักข้อ F ได้คืนมา 22.3 g แต่ของที่เพิ่มหลังจากนั้นกินไปมากกว่า:
แผงปิดหลัง 27.2 g, เสายึดแบต, เสายึด disconnect, ฝาครอบบอร์ด 4.1 g

ยังไม่ต้องตกใจ — มวล CAD ของ**ชิ้นที่ซื้อ**ยังผิดอยู่ เพราะโมเดลวาดเป็นกล่องตัน
(เช่น `TT_Motor_Can` กล่องเหล็กตัน 61.65 g ทั้งที่มอเตอร์ TT จริงทั้งตัวหนักแค่ ~20 g)
ตัวเลขที่เชื่อได้คือวิธีของ `BOM_and_Mass_Report.md` คือ เอามวล CAD เฉพาะชิ้นที่สร้างเอง
บวกมวลจริงจาก BOM ของชิ้นที่ซื้อ — **ตัวเลขแบบนั้นยังไม่ได้คำนวณใหม่หลังเพิ่มแท่นมอเตอร์**
ดังนั้นอย่าเพิ่งยึด 1,504.5 g เป็นคำตอบ มันเป็นตัวเลขฝั่ง "แย่กว่าจริง"

แต่ประเด็นคือ **margin หมดแล้ว** ทางที่ได้ผลที่สุดคือแก้ข้อ B (ปีกหน้า) ซึ่งคืนมา ~380 g

## 🟡 C. ลูกปืนกับเพลาไม่เข้าคู่กัน

`spinner_bearing_OD` = 13 mm คือตลับ **624 รูใน 4 mm** แต่ `spinner_shaft_D` = 3.17 mm (1/8″)
ใส่กันไม่ได้ — เลือก: **623** (3×10×4) กับเพลา 3 mm / **R2-5** (1/8″×3/8″) กับเพลาเดิม /
หรือกลึงเพลาเป็น 4 mm แล้วใช้ 624 (แนะนำอันนี้ เพลาหนาขึ้นรับแรงกระแทกดีกว่า)

## 🟡 D. ตัวเลขพลังงานอาวุธยังใช้ยื่นสนามไม่ได้

มอเตอร์วางขนานเพลาใบมีด ห่าง 49.25 mm = ระบบ**สายพาน** แต่พูลเลย์ยังไม่ได้เลือก
→ **อัตราทดยังไม่ถูกกำหนด** ตัวเลข 10.2 J คิดที่ 1:1 เท่านั้น
พลังงานแปรผันตาม (อัตราทด)² ถ้าทด 2:1 จะกลายเป็น ~40 J

เกี่ยวเนื่อง: cradle เป็น**แท่นยึดตาย** ไม่มีร่องปรับตึงสายพาน ถ้าสายพานที่เลือกต้องปรับตึง
ให้เปลี่ยนรู M3 ทั้งสี่เป็นร่องยาวตามแนวแกน Y หรือใส่ลูกรอกกดสายพานแทน

## 🟢 E. มวลผี 91 g

`Spinner_Sweep_Envelope` + `PCB_Keepout_Envelope` เป็นปริมาตรอ้างอิง ไม่ใช่ชิ้นส่วนจริง
แต่ถูกกำหนดวัสดุ ABS ไว้ รายงานใหม่แยกออกให้แล้ว (1,457.4 → 1,366.3 g)

## ✅ F. ลดน้ำหนัก — ทำแล้ว −22.3 g

เซาะช่องทะลุ ไม่เปลี่ยนวัสดุ

| ชิ้น | ก่อน | หลัง | ลด |
|---|---:|---:|---:|
| `Spinner_Motor_Cradle` | 51.31 g | **35.81 g** | −15.5 g |
| `TT_Motor_Mount_L` | 21.23 g | **17.83 g** | −3.4 g |
| `TT_Motor_Mount_R` | 21.23 g | **17.83 g** | −3.4 g |

- cradle: ช่อง x −9…9, z 8…19 ทะลุตามแกน Y เหลือหลังคาใต้ร่องอาน **5.35 mm**
- แท่นมอเตอร์: ช่องละ 2 ช่องต่อข้าง เลี่ยงรูเกลียวทุกตัว (รูยึดฐานอยู่ที่ z 5–10 ช่องอยู่ z 15.5–26)

**ได้ 22.3 g ไม่ใช่ 99 g** — 99 g คือมวลรวมของชิ้นพวกนี้ ไม่ใช่ยอดที่ลดได้
ถ้าอยากได้อีก ทางเดียวคือเปลี่ยนแท่นมอเตอร์ขับเป็นงานพิมพ์ Nylon:
**ลดได้อีก ~20.6 g** แต่มันรับแรงกระแทกของตัวถังผ่านชุดขับเคลื่อน
**เป็นการตัดสินใจเชิงโครงสร้าง ผมไม่เปลี่ยนให้เอง**

## ✅ ยึด `Battery_Holder` — ทำแล้ว

ถาดลอยอยู่สูงจากพื้น 27.6 mm โดยไม่มีอะไรยึด และใต้กลางถาดเป็น PCB keep-out (x ±30)
จึงตั้งเสาเลี่ยงออกไปที่ **x = ±34** ลอดระหว่าง keep-out กับบอร์ด BEC/driver

เสา Nylon Ø5 สูง 27.6 mm 4 ต้น ที่ (±34, −30) และ (±34, −46)
ขัน M2.5 ลงจากพื้นถาด และขึ้นจากใต้แผ่นฐาน

> ต้องผ่าปากรูบนพื้นถาด — แบตวางทับหัวสกรูพอดี

## ✅ ชุดภาพ + เอกสารมิติ — ทำแล้ว

`exports/views/` 11 ภาพ:
- `view_iso / top / front / right / rear.png`
- `assembly_01…06.png` — ลำดับประกอบ 6 ขั้น (ฐาน → โครง → ชุดขับ → อาวุธ → อิเล็กทรอนิกส์ → ฝา+ค้อน)

`exports/Dimensions_and_Fasteners.md` — envelope, user parameter ทั้งหมด,
ขนาด+มวล+วัสดุรายชิ้น 49 ชิ้น, และ **ตำแหน่งรูทุกรู 142 รู** วัดจาก solid จริง

⚠️ **นี่ไม่ใช่ drawing** — drawing ที่มีเส้นบอกมิติต้องทำใน Fusion Drawing workspace ด้วยมือ
API วางเส้นมิติไม่ได้ ข้อมูลสำหรับผลิตจริงคือไฟล์ DXF กับ STEP

## ✅ ย้าย `Main_Disconnect` + ช่องเข้าถึง — ทำแล้ว

**ทำที่ตำแหน่งเดิมไม่ได้** — `Hammer_Servo` (x ±10, y ±28.75) นั่งบนฝาบนคร่อมสวิตช์พอดี
ช่องไหนที่เลี่ยงรูเสาได้จะกว้างไม่เกิน 14 mm และอยู่ใต้ท้อง servo ทั้งหมด

ย้ายไป **(42, −70)** — นอกเงา servo (servo อยู่ y ≥ −28.75) และมีช่องว่างลงถึงแผ่นฐาน

| | |
|---|---|
| ตำแหน่งใหม่ | x 29.5…54.5, y −80…−60, z 45…55 mm |
| เสายึด | อลูมิเนียม Ø6 สูง **40 mm** 2 ต้น ที่ (32.5, −70) และ (51.5, −70) ลงถึงแผ่นฐาน |
| ช่องเข้าถึง | **20 × 16 mm** กลางที่ (42, −70) ลึกถึงตัวสวิตช์ 28 mm |

ของเก่าเก็บกวาดหมด: ลบเสาแขวน 2 ต้น และ **ลบรู Ø3.4 บนฝาบนพร้อม sketch**
(รายงานยืนยัน `feature deleted`, `sketch deleted`) ไม่เหลือรูกำพร้า

## ✅ แผงปิดหลัง `Rear_Panel` — ทำแล้ว

ด้านหลังเปิดโล่งมาตลอด ตอนนี้ปิดแล้ว

| | |
|---|---|
| ขนาด | x −78…78, y −90…−88, z **5…83 mm** (ชนใต้ฝาบนพอดี) |
| วัสดุ / มวล | Nylon 6 หนา 2 mm / **27.17 g** |
| ยึด | 4× M3 เข้ารูเกลียวแนวนอนในเสามุมหลัง 2 ต้น ที่ z = 20 และ 55 |

รอบแรกผมทำสูงแค่ 65 mm เหลือช่องเปิด 18 mm เหนือแผง ซึ่งยังเป็นทางเข้าของเศษ
เลยยืดให้เต็มความสูง

## ✅ ฝาครอบบอร์ด `Shield_*` — ทำแล้ว

| บอร์ด | ระยะยื่น | มวล |
|---|---:|---:|
| `Shield_RC_Receiver` | 0 mm | 1.21 g |
| `Shield_Wheel_Motor_Drivers` | 1 mm | 1.42 g |
| `Shield_Power_Buck_BEC` | 1 mm | 1.42 g |

แผ่นครอบวางบนสเปเซอร์ในตัว สูงจากบอร์ด 3 mm **ใช้สกรู M2 เดิมของบอร์ดเอง**
(ยาวขึ้น 5 mm) จึงไม่ต้องเจาะแผ่นฐานเพิ่ม

ระยะยื่นถูกตัดอัตโนมัติตามที่ว่างจริง — probe จับได้ว่ายื่น 3 mm จะชนเสายึดแบต
และฝั่ง RC receiver จะชนแผงปิดหลัง

**`ESP32_Control_Board` ไม่ได้ครอบแบบนี้** — keep-out ของมันสูงถึง z = 31.6 และถาดแบต
เริ่มที่ 32.6 เหลือช่อง 1 mm ใส่อะไรไม่ได้ ตัวมันมีถาดแบตครอบอยู่ด้านบนแล้ว

## 📋 งานที่เหลือ (อัปเดต 23:38)

### ต้องคุณตัดสินใจก่อน ผมทำแทนไม่ได้

| # | เรื่อง | ทำไมต้องคุณ |
|---|---|---|
| B | **ปีกหน้า** — ตอนนี้เป็นอลูมิเนียมตันหนา 45 mm ข้างละ 237 g | ต้องเลือกรูปทรง: พับจากแผ่น 2–3 mm, เชื่อม, หรือคงบล็อกตัน คืนน้ำหนัก ~380 g |
| C | **ลูกปืน/เพลาสปินเนอร์** ไม่เข้าคู่กัน (624 รูใน 4 mm vs เพลา 3.17 mm) | เลือก 623+เพลา 3 mm / R2-5+เพลา 1/8″ / กลึงเพลาเป็น 4 mm |
| D | **อัตราทดสายพาน** ยังไม่เลือก → พลังงานอาวุธยังไม่รู้ค่า | ต้องเลือกพูลเลย์จริง แล้วผมคำนวณพลังงานใหม่ให้ |
| — | **ตำแหน่ง `Spinner_ESC`** | ยอมรับเสา 2 ต้น / ย้ายที่ / แขวนจากฝาบน |

### ผมทำต่อได้เลยถ้าสั่ง

| # | เรื่อง |
|---|---|
| F | ลดน้ำหนัก cradle (51 g) + แท่นมอเตอร์ขับ (47.5 g) — เซาะโพรง หรือเปลี่ยนแท่นมอเตอร์เป็นงานพิมพ์ |
| — | `Wire_Clips` + `TPU_Bumpers` — **รอข้อมูลจากคุณ**: เส้นทางสายจริง และจุดที่โดนกระแทกจริง |
| — | แผ่นยาง/TPU รองระหว่างบาร์หนีบกับกระปุกเกียร์ TT |
| — | ทำ exploded view + drawing มิติผลิต (DoD ข้อสุดท้ายใน plan.md) |
| E | เอาวัสดุออกจาก envelope 2 ตัว ให้เลิกนับมวลผี 91 g |

### ต้องให้คนมีประสบการณ์ตรวจ ไม่ใช่งาน CAD

- ขนาด roll pin Ø2 mm ที่ยึดใบมีดเข้าเพลา — ยังไม่ผ่านการคำนวณแรงกระแทก
- การถ่วงสมดุลใบมีดรอบแกน
- เพลา/ลูกปืนรับแรงกระแทก ไม่ใช่แค่หมุนนิ่ง ๆ
- กติกาพลังงานอาวุธและกล่องกันสะเก็ดของสนามที่จะลง

### ลำดับที่แนะนำ

1. **B** (ปีกหน้า) — คืนน้ำหนักมากที่สุด และแก้ B2 ไปในตัว
2. **F** + ช่องเข้าถึง disconnect — งานเครื่องกล ทำพร้อมกันได้
3. **C** เลือกลูกปืน แล้วสั่งของ
4. **D** เลือกพูลเลย์ → ได้ตัวเลขพลังงานจริง → เช็กกติกา
5. **export รอบสุดท้าย** แล้วค่อยส่งร้านตัด

> ข้อ 1 กับ 2 ขยับรูบนแผ่นฐาน **อย่าเพิ่งสั่งตัดจนกว่าจะจบสองข้อนี้**

## เตือนเรื่องความปลอดภัย

ตัวเลขพลังงานเป็นการประมาณเพื่อคัดกรอง ไม่ใช่การรับรองความปลอดภัย
อาวุธหมุนระดับนี้ต้องมีกล่องกันสะเก็ดที่ได้มาตรฐาน ขั้นตอนล็อกอาวุธ
และต้องให้คนที่มีประสบการณ์หุ่นยนต์ต่อสู้ตรวจแบบก่อนสร้างจริง

## รันซ้ำ

สคริปต์เดียวกันอยู่ที่ `fusion_scripts/BattleBotFixes.py` และติดตั้งใน Fusion แล้ว
(Utilities → Scripts and Add-Ins → Scripts → `BattleBotFixes`) รันซ้ำได้:
cradle สร้างใหม่ทุกครั้ง ส่วนรูที่เจาะแล้วและวัสดุที่ตั้งแล้วจะข้าม

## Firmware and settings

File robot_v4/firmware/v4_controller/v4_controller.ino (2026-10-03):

// V4 battlebot controller: ESP32 + Bluetooth gamepad (Bluepad32) + sensors.
//
// Board: "ESP32 Dev Module" from the Bluepad32 board package.
// Libraries: Bluepad32 (board package), ESP32Servo, OneWire, DallasTemperature.
// Drive: 2x DRV8871 (IN1/IN2 PWM), left pair and right pair of JGA25-370 motors.
// Weapon: Hobbywing Skywalker 40A on a 50 Hz servo pulse (1000 us = stop).
// Sensors (see robot_v4/STATUS.md "Sensors" for placement and wiring):
//   GY-521 MPU6050 IMU (I2C) ...... auto upside-down detection + turn-rate limiter
//   A3144 hall + magnet on pulley . weapon rpm ("ready" colour on the pad)
//   2x DS18B20 .................... weapon ESC and front-left drive motor temperature
//   100k/22k divider .............. pack voltage (keeps the ADC below 2.45 V)
// Every sensor is optional: if it is missing or fails, the robot still drives and
// the related feature falls back (e.g. manual inverted toggle with Y).
//
// SAFETY RULES BUILT IN (test every one with the weapon locked before arena use):
//  1. Weapon pulse is 1000 us at boot and whenever no gamepad is connected.
//  2. Failsafe: no gamepad data for FAILSAFE_MS -> drive coast, weapon 1000 us.
//     Sensor code never blocks: I2C read < 1 ms, DS18B20 runs without waiting.
//  3. Weapon needs an arm sequence (hold L1+R1 for 1 s) after every connect.
//  4. Weapon throttle ramps (WEAPON_RAMP_US_PER_S) so spin-up FROM REST stays
//     ~30 A (design_v4.py: 0.64 s to 90 %). The Skywalker has no current limit,
//     and the ramp does NOT protect it after a hit: a rotor knocked to half speed
//     at full throttle can pull ~110 A until it recovers. The slipping round
//     belt is what limits that; measure it on the bench.
//  5. Disarm instantly with the B / Circle button.
//  6. Hot weapon ESC (> ESC_HOT_C) caps weapon throttle at HOT_WEAPON_CAP.
#include <Bluepad32.h>
#include <ESP32Servo.h>
#include <Wire.h>
#include <OneWire.h>
#include <DallasTemperature.h>

// ---- pins (check against the wiring before powering) ----
const int L_IN1 = 25, L_IN2 = 26;   // DRV8871 left
const int R_IN1 = 27, R_IN2 = 14;   // DRV8871 right
const int WEAPON_PIN = 13;          // Skywalker signal; its 5 V BEC feeds ESP32 VIN
const int I2C_SDA = 21, I2C_SCL = 22;
const int HALL_PIN = 32;            // A3144 output: sensor powered from 5 V, open collector pulled up
                                    // to 3.3 V ONLY by an external 10k (never to 5 V)
const int ONEWIRE_PIN = 4;          // DS18B20 data, 4.7k pull-up to 3.3 V
const int VBAT_PIN = 34;            // ADC1 (works while Bluetooth is on)

// ---- control ----
const uint32_t FAILSAFE_MS = 250;
const int WEAPON_MIN_US = 1000, WEAPON_MAX_US = 2000;
const float WEAPON_RAMP_US_PER_S = 1600.0f;  // 0 -> full in 0.63 s, ~30 A peak from rest
const int PWM_FREQ = 20000, PWM_BITS = 10, PWM_MAX = (1 << PWM_BITS) - 1;
const int DEADBAND = 40;                     // stick units out of 512

// ---- sensors ----
const uint8_t MPU_ADDR = 0x68;
const float ACC_LSB_PER_G = 2048.0f;         // +-16 g range
const float GYRO_LSB_PER_DPS = 16.4f;        // +-2000 dps range
const float INVERT_THRESHOLD_G = 0.5f;       // filtered Z beyond +-0.5 g decides the side
const uint32_t INVERT_HOLD_MS = 300;         // must persist this long (hits are short)
const float YAW_LIMIT_DPS = 690.0f;          // 12 rad/s, below the 14.7 rad/s gyro wheel-lift limit
const uint32_t HALL_MIN_PERIOD_US = 2000;    // ignore pulses faster than 30,000 rpm (noise)
const uint32_t HALL_TIMEOUT_US = 200000;     // no pulse for 0.2 s -> 0 rpm
const float READY_RPM = 10000.0f;            // pad turns green above this
const float VBAT_DIVIDER = (100.0f + 22.0f) / 22.0f;   // 12.6 V -> 2.27 V, 10.5 V -> 1.89 V at the pin
const float VBAT_LOW = 10.5f;                // 3S, warn after VBAT_LOW_MS below this
const float VBAT_OK = 10.9f;                 // clear the warning above this
const uint32_t VBAT_LOW_MS = 2000;           // spin-up sag is shorter than this
const float ESC_HOT_C = 80.0f, MOTOR_HOT_C = 90.0f;
const float HOT_WEAPON_CAP = 0.7f;
// DS18B20s are numbered by their ROM code, not by wiring order. Warm one probe with a finger,
// watch the Serial telemetry, and set which index is taped to the weapon ESC.
const int ESC_TEMP_INDEX = 0;

ControllerPtr pad = nullptr;
Servo weapon;
uint32_t lastData = 0;
bool armed = false;
uint32_t armHoldStart = 0;
float weaponUs = WEAPON_MIN_US;
uint32_t lastLoop = 0;

// inverted handling: automatic from the IMU, manual with Y, back to automatic with X
bool inverted = false;
bool autoInvert = true;
bool imuOk = false;
float azFilt = 1.0f, gzDps = 0.0f;
uint32_t sideChangeSince = 0;

// weapon rpm from the hall sensor
volatile uint32_t hallLastUs = 0, hallPeriodUs = 0;
float weaponRpm = 0.0f;

// temperatures and battery
OneWire oneWire(ONEWIRE_PIN);
DallasTemperature temps(&oneWire);
int nTemps = 0;
DeviceAddress tempAddr[2];                   // looked up once in setup(): no bus search per read
bool batLow = false;
uint32_t batBelowSince = 0;
uint8_t warnedMask = 0;                      // rumble once per warning type per connection
float escC = NAN, motorC = NAN, vbat = NAN;
uint32_t tempRequestedAt = 0;

uint8_t ledState = 255;

void IRAM_ATTR onHall() {
  uint32_t now = micros();
  uint32_t dt = now - hallLastUs;
  if (dt >= HALL_MIN_PERIOD_US) {
    hallPeriodUs = dt;
    hallLastUs = now;
  }
}

void onConnected(ControllerPtr c) {
  if (pad == nullptr) { pad = c; armed = false; lastData = millis(); ledState = 255; warnedMask = 0; }
  else c->disconnect();                      // only one driver
}

void onDisconnected(ControllerPtr c) {
  if (c == pad) { pad = nullptr; armed = false; }
}

void setMotor(int in1, int in2, int cmd) {   // cmd -PWM_MAX..PWM_MAX, 0 = coast
  cmd = constrain(cmd, -PWM_MAX, PWM_MAX);
  if (cmd > 0)      { ledcWrite(in1, cmd); ledcWrite(in2, 0); }
  else if (cmd < 0) { ledcWrite(in1, 0);   ledcWrite(in2, -cmd); }
  else              { ledcWrite(in1, 0);   ledcWrite(in2, 0); }
}

void safeStop() {
  setMotor(L_IN1, L_IN2, 0);
  setMotor(R_IN1, R_IN2, 0);
  armed = false;
  weaponUs = WEAPON_MIN_US;
  weapon.writeMicroseconds(WEAPON_MIN_US);
}

int shape(int v) {                           // stick -512..511 -> -PWM_MAX..PWM_MAX
  if (abs(v) < DEADBAND) return 0;
  return map(v, -512, 511, -PWM_MAX, PWM_MAX);
}

// ---------------------------------------------------------------- IMU
void mpuWrite(uint8_t reg, uint8_t val) {
  Wire.beginTransmission(MPU_ADDR);
  Wire.write(reg);
  Wire.write(val);
  Wire.endTransmission();
}

bool imuBegin() {
  Wire.begin(I2C_SDA, I2C_SCL, 400000);
  Wire.setTimeOut(5);                        // ms; a broken I2C line must not stall the loop
  Wire.beginTransmission(MPU_ADDR);
  if (Wire.endTransmission() != 0) return false;
  mpuWrite(0x6B, 0x00);                      // wake up
  mpuWrite(0x1A, 0x03);                      // DLPF ~44 Hz
  mpuWrite(0x1B, 0x18);                      // gyro +-2000 dps
  mpuWrite(0x1C, 0x18);                      // accel +-16 g (hits are large)
  return true;
}

void imuUpdate(float dt) {
  if (!imuOk) return;
  // one burst from ACCEL_ZOUT_H (0x3F): AZ, TEMP, GX, GY, GZ = 10 bytes
  Wire.beginTransmission(MPU_ADDR);
  Wire.write(0x3F);
  if (Wire.endTransmission(false) != 0) return;
  if (Wire.requestFrom((int)MPU_ADDR, 10) != 10) return;
  uint8_t b[10];
  for (int i = 0; i < 10; i++) b[i] = Wire.read();
  int16_t az = (int16_t)((b[0] << 8) | b[1]);
  int16_t gz = (int16_t)((b[8] << 8) | b[9]);

  float a = constrain(dt / 0.15f, 0.0f, 1.0f);           // ~0.15 s low-pass rejects hit spikes
  azFilt += a * (az / ACC_LSB_PER_G - azFilt);
  gzDps = gz / GYRO_LSB_PER_DPS;

  if (!autoInvert) return;
  bool wantInverted = inverted;
  if (azFilt < -INVERT_THRESHOLD_G) wantInverted = true;
  else if (azFilt > INVERT_THRESHOLD_G) wantInverted = false;
  if (wantInverted != inverted) {
    if (sideChangeSince == 0) sideChangeSince = millis();
    if (millis() - sideChangeSince > INVERT_HOLD_MS) { inverted = wantInverted; sideChangeSince = 0; }
  } else {
    sideChangeSince = 0;
  }
}

// ---------------------------------------------------------------- other sensors
void rpmUpdate() {
  noInterrupts();
  uint32_t last = hallLastUs, period = hallPeriodUs;
  interrupts();
  weaponRpm = (period == 0 || micros() - last > HALL_TIMEOUT_US) ? 0.0f : 60.0e6f / period;
}

void slowSensors() {                         // temperatures and battery, ~1 Hz, non-blocking
  uint32_t now = millis();
  if (nTemps > 0) {
    if (tempRequestedAt == 0) {
      temps.requestTemperatures();           // returns at once (setWaitForConversion(false))
      tempRequestedAt = now;
    } else if (now - tempRequestedAt > 250) {  // 10-bit conversion takes 188 ms
      float a = temps.getTempC(tempAddr[ESC_TEMP_INDEX]);
      float b = nTemps > 1 ? temps.getTempC(tempAddr[1 - ESC_TEMP_INDEX]) : DEVICE_DISCONNECTED_C;
      escC = (a == DEVICE_DISCONNECTED_C) ? NAN : a;
      motorC = (b == DEVICE_DISCONNECTED_C) ? NAN : b;
      tempRequestedAt = 0;
    }
  }
  static uint32_t lastV = 0;
  if (now - lastV >= 100) {                  // 10 Hz, lightly filtered so motor surges do not flicker the warning
    lastV = now;
    float v = analogReadMilliVolts(VBAT_PIN) / 1000.0f * VBAT_DIVIDER;
    vbat = isnan(vbat) ? v : vbat + 0.2f * (v - vbat);
    if (vbat > 5.0f && vbat < VBAT_LOW) {      // >5 V: ignore USB-only power on the bench
      if (batBelowSince == 0) batBelowSince = now;
      if (now - batBelowSince > VBAT_LOW_MS) batLow = true;
    } else {
      batBelowSince = 0;
      if (vbat > VBAT_OK) batLow = false;
    }
  }
}

bool escHot() { return !isnan(escC) && escC > ESC_HOT_C; }
bool motorHot() { return !isnan(motorC) && motorC > MOTOR_HOT_C; }
bool batteryLow() { return batLow; }

// pad light bar: blue = safe, yellow = armed, green = weapon at speed,
// purple = something hot, red = battery low. Only sent when it changes.
void updatePadFeedback() {
  uint8_t s;
  if (batteryLow()) s = 4;
  else if (escHot() || motorHot()) s = 3;
  else if (!armed) s = 0;
  else if (weaponRpm >= READY_RPM) s = 2;
  else s = 1;
  if (s == ledState) return;
  static const uint8_t col[5][3] = {{0, 0, 255}, {255, 160, 0}, {0, 255, 0}, {160, 0, 255}, {255, 0, 0}};
  pad->setColorLED(col[s][0], col[s][1], col[s][2]);
  if (s >= 3 && !(warnedMask & (1 << s))) {   // one buzz per warning type per connection
    pad->playDualRumble(0, 300, 0x80, 0x40);
    warnedMask |= 1 << s;
  }
  ledState = s;
}

void telemetry() {                           // bench data over USB serial, 2 Hz
  static uint32_t last = 0;
  if (millis() - last < 500) return;
  last = millis();
  Serial.printf("pad=%d armed=%d inv=%d(%s) az=%.2f gz=%.0fdps rpm=%.0f vbat=%.2f esc=%.1fC motor=%.1fC weapon_us=%.0f\n",
                pad != nullptr, armed, inverted, autoInvert ? "auto" : "manual", azFilt, gzDps,
                weaponRpm, vbat, escC, motorC, weaponUs);
}

// ---------------------------------------------------------------- setup / loop
void setup() {
  Serial.begin(115200);
  weapon.setPeriodHertz(50);
  weapon.attach(WEAPON_PIN, WEAPON_MIN_US, WEAPON_MAX_US);
  weapon.writeMicroseconds(WEAPON_MIN_US);  // first thing: weapon stopped
  for (int p : {L_IN1, L_IN2, R_IN1, R_IN2}) ledcAttach(p, PWM_FREQ, PWM_BITS);
  safeStop();

  imuOk = imuBegin();
  autoInvert = imuOk;
  pinMode(HALL_PIN, INPUT_PULLUP);
  attachInterrupt(digitalPinToInterrupt(HALL_PIN), onHall, FALLING);
  temps.begin();
  nTemps = min((int)temps.getDeviceCount(), 2);
  for (int i = 0; i < nTemps; i++) {
    if (!temps.getAddress(tempAddr[i], i)) { nTemps = i; break; }
  }
  temps.setResolution(10);
  temps.setWaitForConversion(false);
  analogSetPinAttenuation(VBAT_PIN, ADC_11db);
  Serial.printf("IMU %s, %d temperature sensor(s)\n", imuOk ? "OK" : "MISSING (manual invert with Y)", nTemps);

  BP32.setup(&onConnected, &onDisconnected);
  BP32.forgetBluetoothKeys();                // pair fresh each power-up
  lastLoop = millis();
}

void loop() {
  bool fresh = BP32.update();
  uint32_t now = millis();
  float dt = (now - lastLoop) / 1000.0f;
  lastLoop = now;

  imuUpdate(dt);
  rpmUpdate();
  slowSensors();
  telemetry();

  if (pad && pad->isConnected() && fresh && pad->hasData()) lastData = now;
  if (!pad || !pad->isConnected() || now - lastData > FAILSAFE_MS) {
    safeStop();
    delay(5);
    return;
  }

  // ---- arming / disarming ----
  bool l1 = pad->l1(), r1 = pad->r1();
  if (pad->b()) { armed = false; }
  if (!armed && l1 && r1) {
    if (armHoldStart == 0) armHoldStart = now;
    if (now - armHoldStart > 1000) armed = true;
  } else {
    armHoldStart = 0;
  }
  // Y: manual flip (turns automatic mode off). X: back to automatic (needs the IMU).
  static bool lastY = false;
  if (pad->y() && !lastY) { inverted = !inverted; autoInvert = false; }
  lastY = pad->y();
  if (pad->x() && imuOk) autoInvert = true;

  // ---- drive: left stick throttle, right stick steering (arcade) ----
  // Upside down (rolled over) only the throttle sign changes; the side swap and the
  // reversed wheel direction cancel for steering.
  int thr = -shape(pad->axisY());
  int str = shape(pad->axisRX());
  if (inverted) thr = -thr;
  // Turn-rate limiter: with the weapon spinning, gyroscopic torque lifts a wheel above
  // ~14.7 rad/s (design_v4.py). Scale steering down once the IMU sees more than YAW_LIMIT_DPS.
  if (imuOk && weaponRpm > 3000.0f && fabsf(gzDps) > YAW_LIMIT_DPS) {
    str = (int)(str * YAW_LIMIT_DPS / fabsf(gzDps));
  }
  setMotor(L_IN1, L_IN2, thr + str);
  setMotor(R_IN1, R_IN2, thr - str);

  // ---- weapon: right trigger 0..1023, ramp limited up, instant down ----
  float cap = escHot() ? HOT_WEAPON_CAP : 1.0f;
  float target = WEAPON_MIN_US;
  if (armed) target = WEAPON_MIN_US + (WEAPON_MAX_US - WEAPON_MIN_US) * cap * (pad->throttle() / 1023.0f);
  if (target > weaponUs) weaponUs = min(target, weaponUs + WEAPON_RAMP_US_PER_S * dt);
  else weaponUs = target;
  weapon.writeMicroseconds((int)weaponUs);

  updatePadFeedback();
  delay(5);
}

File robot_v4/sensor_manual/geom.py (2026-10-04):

"""V4 geometry for the sensor installation manual.

Every number here is copied from robot_v4/build_robot_v4.py (commit 9321d02) or
computed from those numbers. The manual never types a coordinate by hand.

CAD frame (build_robot_v4.py): x right, y forward (nose +Y), z up, floor z = 0, mm.
Manual frame (ROS REP-103 style): X forward, Y left, Z up.
  Origin O = on the floor, on the left-right centre line, midway between the
  front and rear axles (CAD y = -30).
  X_m = y_cad + 30,  Y_m = -x_cad,  Z_m = z_cad
"""
import math

ORIGIN_Y_CAD = -30.0          # midpoint of WHEEL_Y = (10, -70)


def to_manual(x, y, z):
    return (y - ORIGIN_Y_CAD, -x, z)


# ---- constants straight from build_robot_v4.py ------------------------------
AXLE_Z = 32.0
ROTOR_Y = 95.0
MOTOR_Y = 44.0
WHEEL_R = 32.0
WHEEL_Y = (10.0, -70.0)
TIP_R, BASE_R = 29.5, 23.0
LID_SCREWS_Y = (-95, -15, 55)

TUB = dict(x0=-88, x1=88, y0=-110, y1=64, z0=4, z1=60)   # floor bottom z 4, lid top z 60
FLOOR_TOP_Z = 7.0
LID_UNDERSIDE_Z = 58.0
FRONT_BULKHEAD = dict(y0=62, y1=64)
REAR_WALL = dict(y0=-110, y1=-104)
SIDE_WALL = dict(x_in=80, x_out=88, y0=-110, y1=97)

# skirts (35 deg, 0.8 mm, bottom edge 0.5 mm above floor)
S35, C35 = math.sin(math.radians(35)), math.cos(math.radians(35))
SKIRT_P_TOP = (90.5 + 1.5 * S35, 16.8 - 1.5 * C35 + 0.5)
SKIRT_P_BOT = (90.5 + 16.8 / C35 * S35, 0.5)
SKIRT_T = 0.8
SKIRT_OUT_U = SKIRT_P_BOT[0] + SKIRT_T * C35          # outermost |x| of the side skirts
REAR_SKIRT_OUT_Y = -(SKIRT_OUT_U + 22)                  # rear skirt outermost y
WEDGELET_TIP_Y = 128.0
OVERALL = dict(x0=-SKIRT_OUT_U, x1=SKIRT_OUT_U, y0=REAR_SKIRT_OUT_Y, y1=WEDGELET_TIP_Y, z0=0.0, z1=64.0)

# boxes: name -> (x0, x1, y0, y1, z0, z1)
BOX = {
    'battery':  (-37.5, 37.5, -38, -3, 8, 33),
    'esc':      (-60, -5, -40, -15, 34, 46),
    'esp32':    (4, 55.5, -42, -13.7, 34, 48),
    'drv_l':    (39, 59, -45, -25, 8, 14),
    'drv_r':    (39, 59, -24, -4, 8, 14),
    'imu_pad':  (-10.5, 10.5, -56, -40, 7, 8),
    'imu':      (-10.5, 10.5, -56, -40, 8, 11.5),
    'hall_post': (8.0, 12.0, 40, 48, 7, 43),
    'hall':     (6.5, 8.0, 42, 46, 37, 41),
    'switch':   (66, 80, -34, -26, 20, 30),
    'motor_mount': (-45, -42, 26, 62, 10, 54),
    'skid':     (-20, 20, 64, 74, 1, 4),
    'top_brace': (-33, 33, 64, 74, 57, 60),
    'bot_brace': (-33, 33, 64, 74, 4, 7),
}

# cylinders along x: name -> (x0, x1, y, z, r)
CYL = {
    'weapon_motor': (-41, -5, MOTOR_Y, AXLE_Z, 17.5),
    'pulley':       (-4, 4, MOTOR_Y, AXLE_Z, 13.0),
    'hub':          (-20, 20, ROTOR_Y, AXLE_Z, 15.0),
    'disc_l':       (-26.5, -19.5, ROTOR_Y, AXLE_Z, TIP_R),
    'disc_r':       (19.5, 26.5, ROTOR_Y, AXLE_Z, TIP_R),
}
for wy, pos in zip(WHEEL_Y, ('f', 'r')):
    CYL['motor_%s_l' % pos] = (-56, -4, wy, AXLE_Z, 12.5)
    CYL['motor_%s_r' % pos] = (4, 56, wy, AXLE_Z, 12.5)
    CYL['wheel_%s_l' % pos] = (-78, -62, wy, AXLE_Z, WHEEL_R)
    CYL['wheel_%s_r' % pos] = (62, 78, wy, AXLE_Z, WHEEL_R)

UPRIGHT_PROFILE = [(64, 7), (64, 57), (104, 57), (112, 40), (112, 16.5), (100, 25), (98, 25), (98, 7)]  # (y, z)
UPRIGHT_X = [(-33, -27), (27, 33)]
WEDGELET_PROFILE = [(128, 0.5), (128, 2.5), (100, 22.5), (100, 20.5)]   # (y, z)
WEDGELET_X = [(-88, -27), (27, 88)]

# hall magnet: dia 3 x 2 pressed into the pulley's +x face (x = 4) at r = 7 mm (manufacturing/README.md)
MAGNET_R_ON_PULLEY = 7.0
PULLEY_FACE_X = 4.0
HALL_GAP = BOX['hall'][0] - PULLEY_FACE_X        # 2.5 mm


def centre(b):
    x0, x1, y0, y1, z0, z1 = b
    return ((x0 + x1) / 2, (y0 + y1) / 2, (z0 + z1) / 2)


def fmt(v, nd=1):
    s = ('%.' + str(nd) + 'f') % v
    if '.' in s:
        s = s.rstrip('0').rstrip('.')
    return '0' if s in ('-0', '') else s


# ---- sensor records ---------------------------------------------------------
def sensor_table():
    """Per-sensor reference point in both frames plus distances to real faces."""
    imu = BOX['imu']
    hall = BOX['hall']
    out = {}
    # S1: reference = centre of the PCB underside (sits on the foam)
    cx, cy, _ = centre(imu)
    out['S1'] = dict(cad=(cx, cy, imu[4]), size=(imu[1] - imu[0], imu[3] - imu[2], imu[5] - imu[4]))
    # S2: reference = centre of the TO-92 body
    out['S2'] = dict(cad=centre(hall), size=(hall[1] - hall[0], hall[3] - hall[2], hall[5] - hall[4]))
    for k, v in out.items():
        x, y, z = v['cad']
        v['man'] = to_manual(x, y, z)
        v['d_rear_outer'] = y - TUB['y0']                 # from rear wall outer face (y -110)
        v['d_front_face'] = FRONT_BULKHEAD['y1'] - y       # to front bulkhead front face (y 64)
        v['d_right_outer'] = TUB['x1'] - x                 # from right wall outer face (x 88)
        v['d_left_outer'] = x - TUB['x0']                  # from left wall outer face (x -88)
        v['d_floor_top'] = z - FLOOR_TOP_Z
        v['d_ground'] = z
        v['d_lid'] = LID_UNDERSIDE_Z - z
        v['d_centre_xy'] = math.hypot(*v['man'][:2])
    return out


def selfcheck():
    # front axle centre: CAD (0, 10, 32) -> manual (40, 0, 32)
    assert to_manual(0, 10, 32) == (40.0, 0, 32)
    assert abs(HALL_GAP - 2.5) < 1e-9
    assert abs((OVERALL['x1'] - OVERALL['x0']) - 206) < 1.0, OVERALL
    assert abs((OVERALL['y1'] - OVERALL['y0']) - 253) < 1.0, OVERALL
    # hall centre height = pulley axis + magnet radius, so the magnet passes the sensor centre
    assert centre(BOX['hall'])[2] == AXLE_Z + MAGNET_R_ON_PULLEY
    assert centre(BOX['hall'])[1] == MOTOR_Y
    return True


def route_len(pts):
    return sum(math.dist(a, b) for a, b in zip(pts, pts[1:]))


# Recommended cable routes (CAD frame). Not in the CAD model: these are the manual's recommendation.
ROUTES = {
    # S2 hall: legs up from the TO-92, over the post top, over the right-front drive motor, to the ESP32
    'S2': [(7.25, 44, 41), (7.25, 44, 48), (14, 40, 51), (25, 28, 51), (25, -10, 51), (25, -13.7, 50)],
    # S1 IMU: straight up from the board through the free column behind the battery, over the ESP32
    'S1': [(3, -48, 11.5), (3, -48, 51), (12, -30, 51), (12, -16, 50)],
    # S3/S4 DS18B20 bus: ESP32 front edge -> over the ESC top to its probe -> forward to the FL motor can
    'S3': [(10, -16, 50), (0, -16, 51), (-32.5, -24, 49), (-32.5, -27.5, 46.5)],
    'S4': [(-32.5, -24, 49), (-25, -8, 51), (-20, 2, 49), (-20, 10, 45)],
    # S5 divider tap: removable-link output (right wall) -> ESP32 rear-right corner
    'S5': [(66, -30, 25), (60, -30, 40), (55, -38, 44)],
}
# Power / motor power (schematic paths in the top view, recommendation)
POWER_ROUTES = {
    'batt_to_link': [(37.5, -20, 20), (66, -30, 25)],
    'link_to_esc':  [(66, -30, 30), (60, -12, 50), (0, -12, 52), (-5, -27, 46)],
    'link_to_drv':  [(66, -30, 20), (60, -30, 14)],
}
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

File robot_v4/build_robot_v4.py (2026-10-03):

"""Create the V4 vertical-beater CAD study in Autodesk Fusion and export F3D/STEP.

Concept: invertible 4WD printed chassis (TPU), front dual-disc steel beater
on a dead M8 shaft between two 6 mm 6061 uprights, belt-driven 1:1 by a
D3536 outrunner, 2 mm steel wedgelets. Sizes come from design_v4.py.
Conceptual axes: x right, y forward (nose +Y), z up, mm, floor z = 0.
Bought parts are envelopes (ABS proxy), not supplier CAD.
"""
import adsk.core
import adsk.fusion
import json
import math
import os

OUT = '/Users/jitwisutthobut/Desktop/robot/robot_v4'
AXLE_Z = 32.0
ROTOR_Y = 95.0
MOTOR_Y = 44.0
WHEEL_R = 32.0
WHEEL_Y = (10.0, -70.0)          # wheelbase 80 mm
BASE_R, TIP_R, TOOTH_DEG = 23.0, 29.5, 60.0
# support block under each wedgelet: its top edge is the wedgelet's lower surface
WEDGE_SUPPORT = [(100, 4), (100, 20.5), (106, 20.5 - 6 * 20 / 28), (106, 4)]
BLOCK_WALL_SCREWS = [(80, 13.5), (92, 13.5)]                 # (y, z) side wall -> PETG block
PIN_Y, PIN_Z = 102.0, 14.5                                    # wedgelet hinge axis (along x)
# skirt brackets (printed with the tub) along each side and the rear
SKIRT_TILT = 35.0                                             # deg from vertical, outward-down
SKIRT_T = 0.8                                                 # 5052 aluminium skirt plate thickness (mm)
SKIRT_GAP = 0.5                                               # rigid skirt bottom edge above the floor (mm)
SKIRT_CLIPS_SIDE = [(-90, -75), (-35, -20), (25, 40), (55, 70)]
SKIRT_CLIPS_REAR = [(-65, -50), (-8, 8), (50, 65)]
# carrier section: top edge = plate underside (z = 20.5 - (y - 100) * 20/28), clear of the spine (z <= 11 at y <= 104)
CARRIER = [(100, 11.5), (100, 20.5), (114, 20.5 - 14 * 20 / 28), (114, 8), (105, 8), (104.5, 11.5)]
LID_SCREWS_Y = (-95, -15, 55)
UPRIGHT_SCREWS = [(70, 14), (70, 50), (90, 14), (90, 46)]     # (y, z) through the uprights
MFG = os.path.join(OUT, 'manufacturing')


def cm(mm):
    return mm / 10.0


def point(sketch, x, y, z):
    # Conceptual Z-up (x, length, height) -> Fusion Y-up (x, height, -length).
    return sketch.modelToSketchSpace(adsk.core.Point3D.create(cm(x), cm(z), cm(-y)))


def material(app, exact):
    for library in app.materialLibraries:
        if library.name == 'Fusion Material Library':
            for item in library.materials:
                if item.name == exact:
                    return item
    raise RuntimeError('Missing Fusion material: ' + exact)


def part(parent, name):
    occ = parent.occurrences.addNewComponent(adsk.core.Matrix3D.create())
    occ.component.name = name
    return occ.component


group = part
NEW_BODY = adsk.fusion.FeatureOperations.NewBodyFeatureOperation
JOIN = adsk.fusion.FeatureOperations.JoinFeatureOperation
CUT = adsk.fusion.FeatureOperations.CutFeatureOperation


def extent(inp, distance_mm):
    inp.setOneSideExtent(adsk.fusion.DistanceExtentDefinition.create(
        adsk.core.ValueInput.createByReal(cm(distance_mm))), adsk.fusion.ExtentDirections.PositiveExtentDirection)


def box(parent, name, x0, x1, y0, y1, z0, z1, mat):
    comp = part(parent, name)
    sketch = comp.sketches.add(comp.xZConstructionPlane)
    sketch.sketchCurves.sketchLines.addTwoPointRectangle(point(sketch, x0, y0, 0), point(sketch, x1, y1, 0))
    extrudes = comp.features.extrudeFeatures
    inp = extrudes.createInput(sketch.profiles.item(0), NEW_BODY)
    inp.startExtent = adsk.fusion.OffsetStartDefinition.create(adsk.core.ValueInput.createByReal(cm(z0)))
    extent(inp, z1 - z0)
    body = extrudes.add(inp).bodies.item(0)
    body.name = name
    body.material = mat
    sketch.isVisible = False
    return comp


def extrude_yz(comp, name, loops, x0, x1, operation, body=None):
    """Extrude closed (y, z) polygons/circles along world X from x0 to x1.

    loops: list of ('poly', [(y, z), ...]) or ('circle', (y, z, r)).
    The profile with the largest area is used (outer minus inner loops).
    """
    sketch = comp.sketches.add(comp.yZConstructionPlane)
    sketch.name = name
    for kind, data in loops:
        if kind == 'poly':
            lines = sketch.sketchCurves.sketchLines
            for i, (y, z) in enumerate(data):
                y2, z2 = data[(i + 1) % len(data)]
                lines.addByTwoPoints(point(sketch, 0, y, z), point(sketch, 0, y2, z2))
        else:
            y, z, r = data
            sketch.sketchCurves.sketchCircles.addByCenterRadius(point(sketch, 0, y, z), cm(r))
    # Prefer the profile with the most loops (ring = outer minus bore), then the largest area.
    profs = [sketch.profiles.item(i) for i in range(sketch.profiles.count)]
    most = max(p.profileLoops.count for p in profs)
    best_profile = max((p for p in profs if p.profileLoops.count == most), key=lambda p: p.areaProperties().area)
    extrudes = comp.features.extrudeFeatures
    inp = extrudes.createInput(best_profile, operation)
    inp.startExtent = adsk.fusion.OffsetStartDefinition.create(adsk.core.ValueInput.createByReal(cm(x0)))
    extent(inp, x1 - x0)
    if body is not None:
        inp.participantBodies = [body]
    feature = extrudes.add(inp)
    sketch.isVisible = False
    return feature


def solid_x(parent, name, loops, x0, x1, mat):
    comp = part(parent, name)
    body = extrude_yz(comp, name, loops, x0, x1, NEW_BODY).bodies.item(0)
    body.name = name
    body.material = mat
    return comp, body


def cyl_x(parent, name, x0, x1, y, z, r, mat, bore=None):
    loops = [('circle', (y, z, r))]
    if bore:
        loops.append(('circle', (y, z, bore)))
    return solid_x(parent, name, loops, x0, x1, mat)


def extrude_xz(comp, name, circles, y0, y1, operation, body=None):
    """Extrude circles (x, z, r) along conceptual y from y0 to y1 (sketch on Fusion XY = conceptual x-z)."""
    sketch = comp.sketches.add(comp.xYConstructionPlane)
    sketch.name = name
    for x, z, r in circles:
        sketch.sketchCurves.sketchCircles.addByCenterRadius(point(sketch, x, 0, z), cm(r))
    profiles = adsk.core.ObjectCollection.create()
    for i in range(sketch.profiles.count):
        profiles.add(sketch.profiles.item(i))
    extrudes = comp.features.extrudeFeatures
    inp = extrudes.createInput(profiles, operation)
    # Fusion +Z is conceptual -y: start at -y1 and extrude +Z by (y1 - y0)
    inp.startExtent = adsk.fusion.OffsetStartDefinition.create(adsk.core.ValueInput.createByReal(cm(-y1)))
    extent(inp, y1 - y0)
    if body is not None:
        inp.participantBodies = [body]
    feature = extrudes.add(inp)
    sketch.isVisible = False
    return feature
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

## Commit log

2026-10-01 Add ESP32 mini battlebot V2/V3 CAD, Fusion scripts and simulations
    V2 (robot2) wedge + lifter with lifter hard stops, V3 R3 lifting wedge,
    reports, duel and linkage models.
    [Base_Plate_Al.dxf, Batt_Post_1.stl, Batt_Post_2.stl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]
2026-10-03 Add V4 vertical-beater battlebot: CAD, sizing, matchup screen, firmware, manufacturing files
    V4 follows the new rules (5–6k THB, 1–2 kg, all weapons, plastic/tile floor):
    dual-disc steel beater (~57 J, 1:1 round belt from a D3536), invertible 4WD
    JGA25-370 drive, printed TPU tub, steel wedgelets on PETG blocks, ESP32 +
    Bluepad32 gamepad control.
    - build_robot_v4.py builds the Fusion model, checks interference and rotor
    sweep (42 bodies, 0 hits), and exports F3D/STEP plus manufacturing DXF
    (5 laser-cut parts) and STL (6 printed parts)
    - design_v4.py: weapon energy, firmware ramp current, gyro, bite, drive,
    mass budget from CAD (~1.89 kg), shaft check (M8 12.9 needed)
    - matchup_scre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
    [ROBOT_V4_Beater.f3d, ROBOT_V4_Beater.step, V4_Beater_Disc_6mm_steel_x2.dxf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]
2026-10-03 Fill in remaining V4 BOM prices
    Battery (GNB 3S 850 mAh 80C), PU round belt, heat-set inserts, M8x70 12.9,
    XT30/wiring with an XT30 removable link instead of an imported FingerTech
    switch. Full-buy total ~6,224 THB; with the owned ESP32 and charger ~5,465 THB.
    The laser-cut/machining quote is still an estimate.
2026-10-03 Add V4 sensors to CAD and firmware
    CAD: GY-521 IMU on a foam pad behind the battery (battery moved forward),
    A3144 hall sensor on a PETG post 2.5 mm from the weapon motor pulley.
    46 bodies, no interference; new STL for the hall post.
    Firmware: IMU auto-invert (0.3 s hold) with Y/X manual override, turn-rate
    limiter while the weapon spins, weapon rpm from the hall sensor, DS18B20 ESC
    and motor temperatures (stored addresses, non-blocking), pack voltage on a
    100k/22k divider with 2 s low-battery hysteresis, pad light bar and one-shot
    rumble, serial telemetry. Still not compiled; needs OneWire and
    DallasTemperature.
    Docs: sensor placement and wiring (hall on 5 V, output pulled up to 3.3 V
    onl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
    [ROBOT_V4_Beater.f3d, ROBOT_V4_Beater.step, V4_Beater_Disc_6mm_steel_x2.dxf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]
2026-10-03 Add V2 vs R3 vs V4 three-way duel screen and report
    Reduced-order Monte Carlo + match model (not 3D physics). Reuses
    robot_v3/duel_sim for V2 vs R3 (regression-checked against its
    results.json), V4 geometry from the CAD, tile/plastic floor friction for
    all robots, and the solved V2 linkage force.
    Base assumptions: V4 beats V2 and R3 (77-100%). Pessimistic V4 hit
    transfer: V2 beats V4 (57-81%), V4 and R3 about even. Deciding fact: how
    much energy the rotor still delivers when a low wedge is already under the
    wedgelets. Also a V4 side-skirt study (4 mm edge -> hinged skirt cuts
    opponents getting under from ~100% to 7-24%).
2026-10-03 Add hinged skirts and hinged wedgelets to V4
    Skirts: 1 mm Al plates on the sides and rear hang from a 1.5 mm wire hinge
    and rest on the floor (opponents getting under V4's flank: 98-100% ->
    7-24%). Lid thinned to 2 mm and wheel hubs lightened to pay for them.
    Wedgelets: steel plates now ride on PETG carriers pivoting on a 3 mm pin
    through fixed PETG knuckles; the tip rests on the floor. Swing checked in
    Fusion (check_wedgelet_swing.py): free from -2 to +14 deg, the upright is
    the up-stop at ~15-16 deg. Side walls, side blocks and rails trimmed for
    the swing. 58 bodies, no interference, mass ~1,891 g.
    Three-way sim: with both, V4 beats V2 and R3 under base assumptions
    (90-100%) and stays ah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
    [ROBOT_V4_Beater.f3d, ROBOT_V4_Beater.step, V4_Beater_Disc_6mm_steel_x2.dxf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]
2026-10-03 Detail the V4 skirt hinge and retain the wedgelet pins
    Skirt hinge: 1.5 mm spring-steel wire through knuckles printed on the tub
    (4 per side, 4 at the rear) and PETG clips (4 per side, 3 at the rear)
    bolted to the plates with M2; plate DXFs now carry the clip holes. Swing
    check (check_skirt_swing.py): the wall stops inward rotation within 1 deg,
    outward is free to ~25 deg.
    Wedgelet pins: 57 mm, inner end stops 0.5 mm from the upright, outer end
    takes a DIN 6799 2.3 E-clip in a 0.6 mm groove. Wedgelet swing unchanged
    (-2 to +14 deg free, upright stop ~15-16 deg).
    71 bodies, no interference, mass ~1,891 g, budget ~5,840 THB.
    [ROBOT_V4_Beater.f3d, ROBOT_V4_Beater.step, V4_Beater_Disc_6mm_steel_x2.dxf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]
2026-10-03 Add MuJoCo 3D duel sim and fix V4 issues it found
    robot_v4/mujoco_sim: primitive-geometry MuJoCo models of V2, R3 and V4
    (wheels, DC motors with back-EMF, rate-limited lifter servos, V4 rotor
    with the D3536 model and firmware ramp, hinged wedgelets and skirts).
    Single-robot validation, timestep convergence (dt 2e-5; contact
    stiffness matters more than dt), 576 random-start engagements across
    friction, contact stiffness and arena size, a flank/rear attack test,
    and four short clips. Report in Thai: mujoco_sim/REPORT.md.
    Design problems found and fixed in CAD:
    - straight-hanging skirts jammed as struts and carried the robot ->
    skirts now 0.8 mm plates on 35 deg slanted C-clips (robot 206 mm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
    [ROBOT_V4_Beater.f3d, ROBOT_V4_Beater.step, V4_Beater_Disc_6mm_steel_x2.dxf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]
2026-10-03 V4: rigid tilted skirts; test fixes for low wedges under the rotor
    Skirts: hinged versions let R3's wedge tip slip under and lever the plate
    up (flank 66%, rear 100%); a spring fixed that but put ~20% of the weight
    on the skirts. Rigid 35 deg skirts 0.5 mm off the floor, on brackets
    printed with the tub: 0% for V2 and R3 at any height from 0 to 1.5 mm,
    push 8.5 N. Wire, knuckles and clips removed; mass ~1,889 g.
    Rotor vs low wedges: tried a centre wedgelet between the discs, faster
    drive, a 1.5:1 weapon belt and lower teeth. None lets the rotor launch
    R3's 25 deg plow; a parked opponent is barely launched by any variant
    (too little bite under a low edge). Design left unchanged; results in
    m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
    [ROBOT_V4_Beater.f3d, ROBOT_V4_Beater.step, V4_Beater_Disc_6mm_steel_x2.dxf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]
2026-10-04 Add V4 sensor installation manual and PC simulation guide
    Sensor manual (robot_v4/V4_Sensor_Installation_Manual_TH.pdf, Thai, 41
    pages): position, angle, mounting, wiring, routing, calibration, tests and
    checklist for the five V4 sensors (GY-521 IMU, A3144 hall, two DS18B20,
    battery divider). Coordinates come from build_robot_v4.py via
    sensor_manual/geom.py; values not in the CAD are blank fields to measure.
    V4 has no ranging sensors, so the coverage, blind-spot and safety-zone
    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
2026-10-05 Document V4 print readiness, open todo list, and fix stale notes
    - Add print-readiness section to manufacturing README (small parts printable, TPU tub/lid blocked)
    - Correct hub bearing bore tolerance from H7 to N7 (press fit)
    - Replace outdated "no 3D simulation" limitation now that MuJoCo sim exists
    - Append consolidated open-work list to V4 STATUS
    - Update README weight/budget to current competition rules
2026-10-08 Add V4 print R1/R2 drafts and Thai parts procurement package
    [Beater_Disc_L.dxf, Beater_Disc_L.step, Beater_Hub_6061_D30.step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]
2026-10-10 Prepare V4 R3 draft and lock approved Z-up Fusion orientation
    [Beater_Disc_L.dxf, Beater_Disc_L.step, Beater_Hub_6061_D30.step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]
2026-10-13 Re-run V4 duels and low-wedge tests on the R3 print revision
    run_duels_r3.py and wedge_test_r3.py apply print_revision/simulate.configure()
    (R3 CAD mass/inertia, axles, SURPASS 1300 KV) in each worker and repeat the
    archived grids and seeds, plus 11.1 V and 40 A current-cap controls.
    R3 wins more duels (vs R3 wedge 27% -> 79%, vs V2 35% -> 56-62%), and the
    gain holds with the 40 A cap. The beater still cannot launch a low wedge;
    none of the earlier fixes changes that on R3.
2026-10-13 Add R3 calculation sheet and low-wedge option simulations
    r3_calc.py computes weapon energy, spin-up and post-hit current, gyro and
    spin-up pitch, bite, sloped-face impulse direction, impact demand,
    part capacities, match energy, per-wheel push and mass/balance levers
    from the R3 build (spin-up ODE matches simulation.json). CALC_R3.md
    summarises it in Thai.
    wedge_options_r3.py simulates mass/balance-checked wedgelet variants and a
    big/slow rotor (64 paired seeds x 2 contact stiffnesses, 40 A cap);
    options_calc.py adds plate pry strength and 1-tooth rotor unbalance.
2026-10-18 Add R3 body-material calc and wedge-option duel results
    Sheet-body material study (steel/Al/Ti/PC vs the TPU tub, mass and rear
    load) and the MuJoCo duels for the low-wedge options on R3, with the
    CALC_R3 section 11 summary.
2026-10-18 Fix R3 wedgelet thickness and upright edge taps
    - Wedgelet is now a 1.6 mm plate measured perpendicular to its faces
    (was 2 mm vertical = 1.63 mm real), spring steel, M3 ISO 7046 flat
    head with a 5.5 mm countersink leaving 0.55 mm land.
    - Brace M3 edge taps are modelled in the uprights (x +-30, y 69,
    drill 2.5x8, thread 6); the rear side taps move y 70 -> 75 so the
    two no longer intersect (min wall 2.77 mm).
    - Rebuilt output_R3 (build 5dfa96dc: 1973.05 g, rear load 10.615%)
    and refreshed the Z-up Fusion reference.
2026-10-18 Add 3 mm polycarbonate body rev 3 for R3
    CNC-routed PC panels (3 mm, 2 mm bulkheads) with PETG cradles, side
    blocks, cleats and skirt brackets replacing the TPU tub and lid.
    Expected 1977.64 g, rear load 10.913%, min chassis SF 1.82 for 0.5 m
    drops and the 2.6 kN weapon hit. Includes dimensioned drawings and a
    Thai work order, gated BLOCKED until parts are measured and tested.
2026-10-18 Add gated production package for R3 laser-cut metal parts
    Copies the R3 DXF/STEP unchanged (SHA-checked), draws each part with a
    hole table and edge taps from the STEP, and checks release gates:
    standard sheet thickness, countersink land, hole-to-hole wall, mass,
    rear load and unmeasured motor/shaft values. Current status is
    BLOCKED only on 8 unmeasured hardware values.
2026-10-18 Partial release of R3: metal and PC parts that do not depend on motors
    The user released every part whose geometry does not depend on the
    unmeasured motors (PRODUCTION/RELEASE_DECISION.json, tied to build
    5dfa96dc). Two risks are accepted: the upright L motor relief uses the
    catalogue motor diameter, and the 8.2 mm bore fits a standard M8 bolt.
    - make_metal_production_package.py writes V4_R3_METAL_RELEASED
    (M01-M05, M07-M09, accepted risks on the work order) and keeps M06 in
    V4_R3_METAL_BLOCKED. It stops if the decision is for another build,
    names an unknown part, or releases a part that still fails a gate.
    Chrome path can be set with CHROME.
    - PC body sheets stamp released panels R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
2026-10-19 Release R3 weapon motor mount M06 on catalogue motor values
    The user chose to release M06 complete before the motors are measured.
    RELEASE_DECISION.json now lists M06 as released and records the five
    catalogue/guessed values it relies on as accepted risks (19 x 25 mm M3
    pattern, guessed 10 mm boss, 25 mm front drive motors). All nine metal
    parts are in V4_R3_METAL_RELEASED; the BLOCKED package is gone.
    Claude-Session: https://claude.ai/code/session_01KigVh8VNw48kWh4Be76BwC
2026-10-19 Switch R3 drive motors to ORTECH JB361 and release all parts
    The user picked the JB361 (sources.json R3-10) and asked for every
    remaining value to be chosen so the whole robot can be built.
    - Hub: the JB361 shaft projects 11.5 mm (2.5 mm boss, D-flat on the
    outer 8 mm), short of the old 16 mm requirement. The hub face moves in
    to x 61.5 and a D9 nose through a D10 counterbore in the motor wall
    (TPU tub and PC cradle) carries the D-bore to the start of the flat:
    7.8 mm engagement, minimum 7.5. The set screw moves to 2.5 mm from
    the shaft tip. New hardware key shaft_flat_length_mm (catalogue 8).
    - Hubs print outer face down on both sides (nose up); tyres unchanged.
    - Fit values chos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
2026-10-21 Release R3 parts that do not depend on unmeasured motors
    User decision 2026-10-19 (RELEASE_DECISION.json): release now, hold the
    motor-dependent parts. PRODUCTION/RELEASE_2026-10-19 has one zip per shop:
    - 01_LASER_METAL: M01-M05, M07-M09 (M06 motor plate held)
    - 02_CNC_PC: 7 PC panels, RELEASED drawings, Thai order with sheet
    thickness acceptance 2.9-3.1 / 1.9-2.1 mm
    - 03_LATHE: hub, spacers, hinge pins (motor pulley held)
    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
2026-10-21 Add PETG frame print package for the R3 PC body
    User request 2026-10-21 (FRAME_PRINT_DECISION.json): frame production
    files now. PRODUCTION/RELEASE_2026-10-21/05_PRINT_FRAME_PETG has the 29
    PETG prints that join the PC panels and do not depend on motors
    (14 cleats, 11 skirt brackets, 2 weapon side blocks, 2 wedgelet blocks),
    copied unchanged and SHA-checked, plus 19 insert/hinge-pin coupons and a
    Thai order. Insert holes are still trial values (M2.5 D3.4, M3 D4.6,
    hinge pin +0.2), so the order makes the shop print the coupons first and
    stop if those sizes fail. Motor cradles, saddles and lid bars stay held.
    The 2026-10-19 packages are untouched.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
2026-10-21 Add welded-steel-frame mass calcs and R4-steel concept (set A)
    r3/calc/steel_frame_calc: 21 welded steel frame layouts on the R3 PC body
    all exceed 2000 g (+18 to +713 g).
    r4_steel/calc/steel_r4_calc: budget from fixed R3 mass (1303.2 g) plus
    bought replacements for every printed part; an uncut steel version is
    2357.9 g. No 4WD set reaches the 1950 g target. User chose set A on
    2026-10-21: 2WD front drive + 2 mm PC skins + 3S 650 mAh, 1911.6 g,
    weapon unchanged at 97 J, push 7.84 N. README_TH.md lists the
    assumptions (tube wall, wheel mass, battery C rating, 2WD rocking).
2026-10-21 Add R4-steel set A concept CAD: welded steel frame, 2WD
    build_r4_steel.py rebuilds R3 in memory, removes the TPU body, both rear
    drive motors and every printed part, and adds a 10x10x1.0 welded tube
    frame (rails, crosses, fork arms, hinge beams, 4 posts, top rear cross
    and front stubs that clear the weapon motor), 1.5 mm tabs on the real
    interfaces (upright taps, JGA25 face, M06, wedgelet hinge, battery),
    2 mm PC skins and bought wheel/battery/standoff envelopes. Wedgelet
    carriers and hall post become 6061; M06 gets a notch over the cross.
    Checks: 0 interferences, every frame member touches another, upright
    screw heads clear. 1845.6 g, CG y 20.4 (drive wheels 95.3 %), push
    7.81 N, 1102 mm of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
2026-10-21 Add R4-steel welding-shop package; seat top members on the posts
    make_weld_package.py rebuilds the CAD and writes RFQ_WELD/ + RFQ_WELD.zip:
    a Thai drawing with member IDs (F01-F15 tubes, T01-T17 tabs), datum at
    the rear-left-bottom corner of F01, plan/side/rear views, tube cut list
    with positions, plate list, 38 welds taken from CAD face contacts,
    assembly order with Ø3/Ø8 alignment rods, tolerances, shop questions
    and what is still missing; 21 tab DXFs (L tabs split into a/b plates)
    and FRAME_WELDMENT.step. Marked for quote / design review, not for
    welding.
    build_r4_steel.py now lists every welded joint by contact area and
    rejects edge-only contacts. That found the top rear cross and the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
2026-10-21 Rebuild R4-steel on main's R3 (ORTECH JB361 drive motors)
    The JB361 face sits at |x| 56 with a D7 x 2.5 boss and an 11.5 mm shaft
    (D flat on the outer 8 mm). The bought wheel moves in to |x| 59.5..75.5
    so its hub engages the whole flat, the rails move in to |x| 48..58 to
    clear it, and the electronics plate narrows to |x| 58. T01/T08 get the
    catalogue mount holes (2 x M3 at +-8.5 mm about the shaft, D3.4) next to
    the D8.5 boss hole. Checks: 0 interferences, 0 floating or edge-only
    joints. 1855.1 g, CG y 20.2, drive wheels 95.8 %. Steel calcs rerun on
    the new R3 build (99dc7481); weld package regenerated.
2026-10-21 Close R4-steel pre-weld items: strength, skirts, motors, wedgelet, 2WD sim
    - frame_strength_calc.py (R3 load cases: 2.6 kN hit, 5.2 kN check, 0.5 m
    drops). The first frame failed (fork arm SF 1.1, cross torsion 0.9,
    web weld 0.94). The rails now run unbroken from the rear cross to the
    hinge beam at 10x10x1.5, and the upright web sits on a flange with two
    rungs into the rail, welded both sides. Min design SF 1.51; drops pass.
    The 5.2 kN check bends the rails (0.76). Upward push 1.11 is reported
    as non-credible for a front-teeth-up rotor.
    - Drive motors: JB361 face holes (2 x M3 @ 17 + D8.5 boss + D5.5 gearbox
    screw heads). A tube motor cross, a clamp post and a clamp bar with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
2026-10-21 Add R4-steel drive wheel: turned 6061 hub on JIS P52 O-ring tyres
    User choice 2026-10-21: keep the 16 mm wheel slot and main's hub
    pattern. There is no stock tyre with a 44 mm bore, so the tyre is two
    NBR70 JIS B 2401 P52 O-rings (51.6 x 5.7) in grooves on a 6061 hub:
    groove root D52.8 (2.33 % stretch), lands D57, tyre OD 64.07. The hub
    keeps main's D-bore (D4.10, flat 1.55) and the radial M3 set screw
    2.5 mm from the shaft tip, tapped in the aluminium with a D3.5 key
    hole through the inner groove root. Its five lightening holes sit at
    60..300 deg, so the left and right hubs are the same part.
    Wheel 39.9 g (hub 28.0 + 2 x 5.95), robot 1918.4 g, no interferences.
    Strength: hub web SF 23.7, D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
2026-10-21 Release the R4-steel frame for welding (rev W1)
    WELD_RELEASE/ + WELD_RELEASE.zip replace the RFQ_WELD quote package.
    Each open item was sorted by whether it changes a welded part:
    - JB361 mount holes (vendor drawing only, motor unmeasured): T01/T11
    are laser-cut with the D8.5 boss hole only, which still carries the
    D8 jig rod. The owner drills 2 x M3 (D3.6 + washer, for hand-drill
    error) and 2 x D5.5 per plate after welding, from the real motor.
    The drawing lists the positions, and build_report.json has
    drill_after_weld. FRAME_WELDMENT.step, the DXFs and the 3D view show
    the as-welded plates. The robot STEP keeps the holes.
    - Wheel: does not affect the weldment. A 65x26 wheel pl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
2026-10-21 Add a simple dimensioned weld sketch for the shop
    The welder found WELD_DRAWING_TH.pdf (coordinate tables) too hard to
    read. weld_sketch.py draws WELD_SKETCH_TH.pdf: 3 landscape pages with
    chained dimensions from the rear-left corner, every number from the
    as-welded CAD bounding boxes:
    1. bottom frame from above + cut list (identical tubes grouped)
    2. rear view (posts, top cross) + section at the motor cross (T01/T11
    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
2026-10-21 Add all-round 3D views to the weld sketch
    The shop liked WELD_SKETCH_TH.pdf and asked for 3D views from every
    side. weld_sketch.py adds two pages of shaded views of the as-welded
    frame, labelled with every tube id plus T01/T11, T02/T12 and T23,
    and with a nose arrow:
    4. from above at the four corners
    5. low from the front and the right side, plus two from underneath
    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
2026-10-27 Add R4-DIY: home-built steel frame for a stick welder (rev D1)
    R4-steel set A rebuilt from common-shop stock: 12x12x1.2 black tube,
    1.6/2.3 sheet and 2"x1/8" flat bar, welded with ARC. The weapon uprights
    are welded steel, the wedgelets have bent hinge ears on an M3 pin, and
    the rear cage is removed (user choice). CAD is 1,979.8 g with no
    interference, min design SF 2.03 counting only stitch welds an electrode
    can reach. The side PC wall is open: it deflects 7.5 mm under an 8 N
    skirt push. DIY_PACKAGE has the Thai build guide, 1:1 templates, DXF and
    lathe files. The 2WD MuJoCo sim takes R4_VARIANT=r4_diy; W1 output is
    unchanged. W1 (r4_steel) files are untouched.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
2026-10-27 Add V5 concept: SawBlaze-style hammersaw, budget build and CAD
    V5 is built in addition to V4. SawBlaze gives layout ratios only; every
    part is sized for the 1-2 kg class.
    - design_v5.py: weapon, arm/servo, drive, forks, delivery and matchup
    calcs; reads disc/arm inertia and self-right levers from the CAD
    - budget_cuts_v5.py: DIY/shared-part cuts with Thai prices found
    2026-10-27 (extra cash for V5 4,265 THB)
    - cad/build_v5.py: concept CAD (Z up, nose +Y) with interference, arm
    swing, disc sweep, fork swing, hit load path and self-right checks;
    STEP, preview and report in cad/output
    - V5_CONCEPT.md: Thai report
2026-10-27 Add V5 cut files and fix the saw-disc tooth direction
    - cad/cut_files_v5.py: 1:1 DXF per steel part (layers CUT/HOLES, mm), a
    2-page A4 actual-size PDF template set and the cut list (md/csv), all
    taken from the checked CAD solids
    - build_v5.py: mirror the disc outline so the radial tooth faces lead
    under +X spin (front teeth up); mass and inertia are unchanged
    - the template marks the disc spin direction
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2026-10-27 Add a V4 vs V5 duel screen
    Reduced-order Monte Carlo using three_way_sim's match model, with V4 as
    the R4-DIY build and V5 as the budget concept CAD (fork bars, 4 mm front,
    PETG hinge blocks, 70 J disc with a 0.29 s strike). V4 wins about 90 %
    (median); no single ASSUMED input flips it. Includes a sweep, a V5 best
    case and a V5-with-fixes variant, plus a Thai report.
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2026-10-27 Add V4 R5-AL: bolted aluminium frame, no lathe parts
    User rule 2026-10-27: aluminium by default, steel only where a number needs
    it, stainless where it is better, no lathe parts.
    - frame 12.7x12.7x2.0 Al (6063-T6 minimum; T5 fails the 5.2 kN check),
    bolted instead of welded; R3's bolted 6061 weapon module back in, tied to
    the frame by Al rungs and angle feet (4 x M4 per side)
    - rotor hub: 3/4" steel pipe welded to the discs (a printed hub cannot carry
    the ~122 N m half-hit torque); 608s inside the pipe
    - printed PETG spacers, motor pulley and wheel hubs replace turned 6061
    - mid-wall supports fix the PC side-wall deflection (7.5 -> 1.5 mm)
    - 1,837.5 g (-142 g), 0 interferences, min des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
2026-10-27 R5-AL: real bolted joints for the weapon module and the tabs
    - solid 12.7 Al bar rung (supported M4 in shear), riser and foot angles in
    3 mm 6061: 3 x M4 8.8 per side, positions written to build_report
    - calc reads those positions and adds tear-out: design SF 3.52-4.47, check
    1.76-2.24; foot leg A, drive-motor tab legs and hinge-tab legs checked
    - drive-motor tabs get legs on the rail top; hinge tabs get legs on the beam
    front face under the pin bolt; hinge beam lengthened to x 33.5..91
    - 1,848.8 g, 0 interferences, wedgelets swing -20..+15 deg
    - README: borrowed rail moments flagged; weld the rotor before fitting bearings
2026-10-28 R5-AL rev F: every joint drilled, corner cleats, assembly guide PDF
    - CAD: 80 fixings with holes (rivnut / clearance / M4 tap), 11 corner
    cleats, bent 5052 hinge base, legs on wall tabs and the clamp post,
    lid corner angles, fixing holes in the PC skins and electronics plate
    - the foot angle gets a leg on the rail (the L bulkhead corner has no
    room for a cleat); counted fasteners replace the joint allowance
    - 1,788 g, 0 interferences, wedgelets swing -20..+15 deg, calcs pass
    - guide/make_guide.py: Thai A4 assembly guide (10 steps, tests, fixing
    table) from the CAD, printed with headless Chrome
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
